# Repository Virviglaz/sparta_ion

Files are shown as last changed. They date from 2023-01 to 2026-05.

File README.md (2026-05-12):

# Sparta ION Repair & Restoration Project

This project is a functional, production-ready fork of the [InfantEudora/sparta_ion](https://github.com) repository.

## Overview

This repository implements a custom approach to repairing and restoring the functionality of all generations of the e-bikes popular in the Netherlands that feature the iconic **"banana-shaped" battery** and a **rear hub motor** (e.g., Sparta ION, Batavus, Koga).

## What's Inside

Everything needed to replicate or repair the electronics is included:

*   **Schematics:** Detailed circuit diagrams.
*   **PCB Files:** Design files ready for manufacturing (Gerber files).
*   **Firmware:** Source code and binaries for the microcontrollers.
*   **Documentation:** Step-by-step instructions for assembly, flashing, and system configuration. (in progress)

## Getting Started

1.  Review the **ion2\HW** to understand the hardware modifications.
2.  Order PCBs using the provided files in the `ion2\HW\BATT_ctrl_v3\Gerbers3.4` directory.
3.  Flash the microcontrollers using the code in the `ion2\batt_ctrl` and `ion2\bldc_mmu_firmware` folders.
4.  Follow the **ion2\docs** for final installation and tuning.

## Acknowledgments

This work is based on the original research and development found in the [sparta_ion](https://github.com) project.
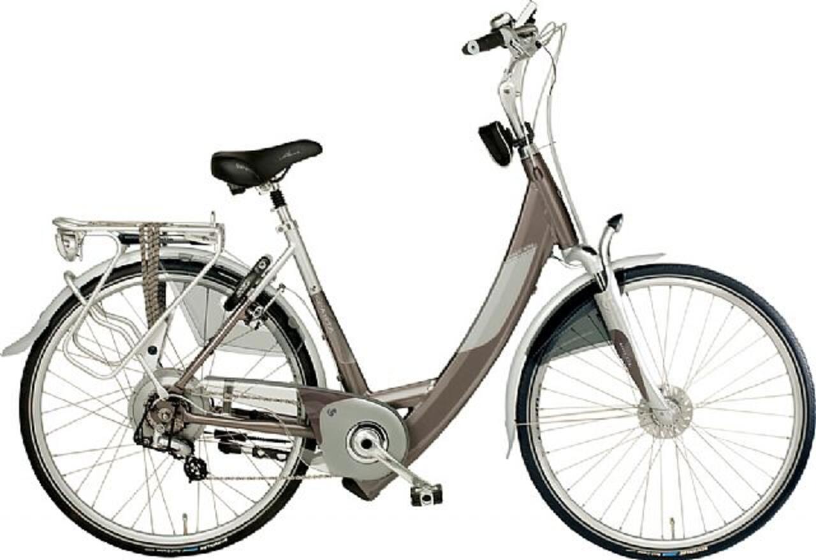
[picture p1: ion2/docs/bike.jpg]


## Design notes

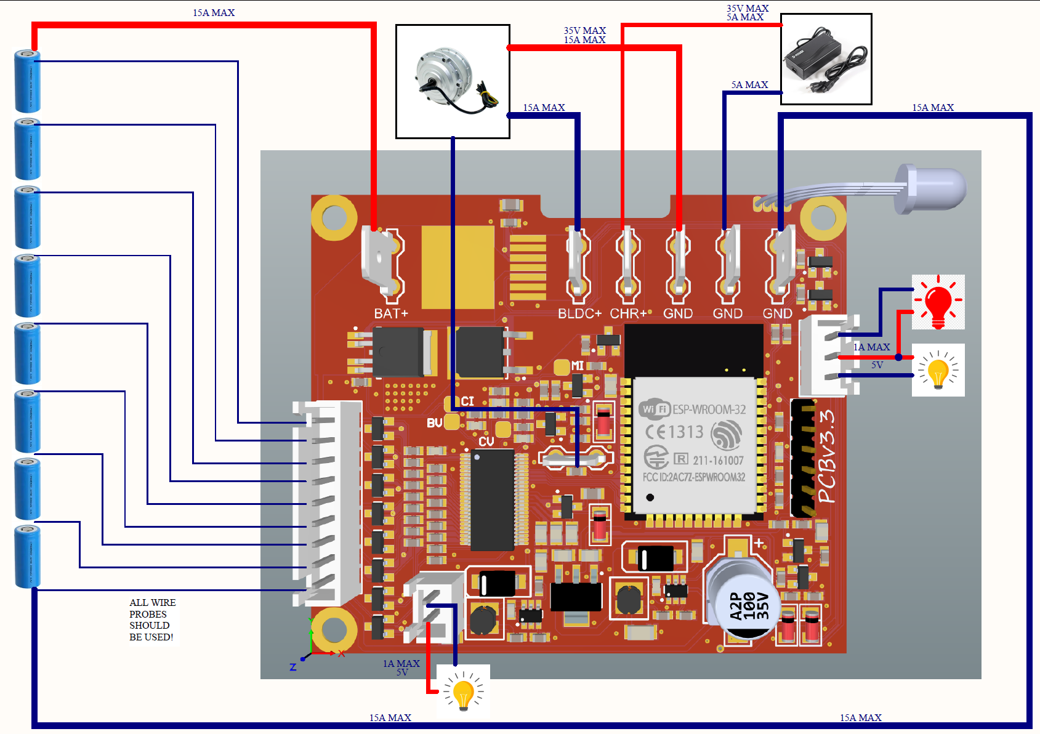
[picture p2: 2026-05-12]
ion2/docs/batt_ctrl_schematic.PNG

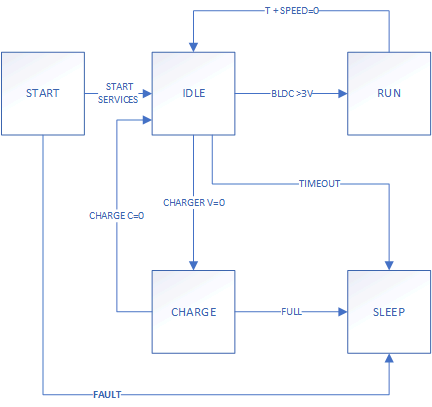
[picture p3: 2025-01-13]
ion2/docs/app_state_machine.png

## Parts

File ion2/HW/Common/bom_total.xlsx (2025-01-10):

Comment | Designator | Footprint | JLCPCB Part # | Qnty BLDC | Qnty BMS | sum | ordered
100 |  | 0603 | C2076611 | 6 | 0 | 6 | 60
4k7 |  |  | RT0603CRD074K7L | 1 | 1 | 2 | 20
1k 1% |  |  | MCT06030C1001FP500 | 1 | 3 | 4 | 40
10k 1% |  |  | C304079 | 3 | 3 | 6 | 60
390k |  |  | C403198 | 1 | 1 | 2 | 20
1k |  |  | C965150 | 11 | 12 | 23 | 230
10k |  |  | C465463 | 2 | 7 | 9 | 90
270k |  |  | C137642 | 1 | 0 | 1 | 10
220 |  |  | C5140263 | 1 | 0 | 1 | 10
47k |  |  | C2934399 | 1 | 1 | 2 | 20
100k 1% |  |  | C319967 | 0 | 2 | 2 | 20
100k |  |  | C319967 | 0 | 2 | 2 | 20
56k |  |  | C278629 | 0 | 2 | 2 | 20
100n |  |  | C323570 | 7 | 16 | 23 | 230
22 |  | 0805 | C3016596 | 0 | 8 | 8 | 80
6u8 |  | 0805 | C39060 | 0 | 9 | 9 | 90

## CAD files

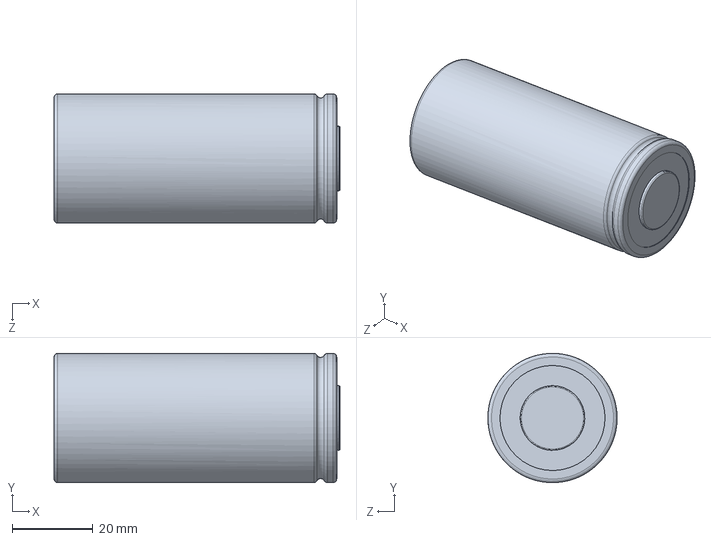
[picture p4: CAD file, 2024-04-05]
ion2/HW/SolidWorks/BatteryAssy1.SLDASM
70.8 x 32.0 x 32.0 mm

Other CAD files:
ion2/HW/SolidWorks/LiFePo4_32700.SLDPRT

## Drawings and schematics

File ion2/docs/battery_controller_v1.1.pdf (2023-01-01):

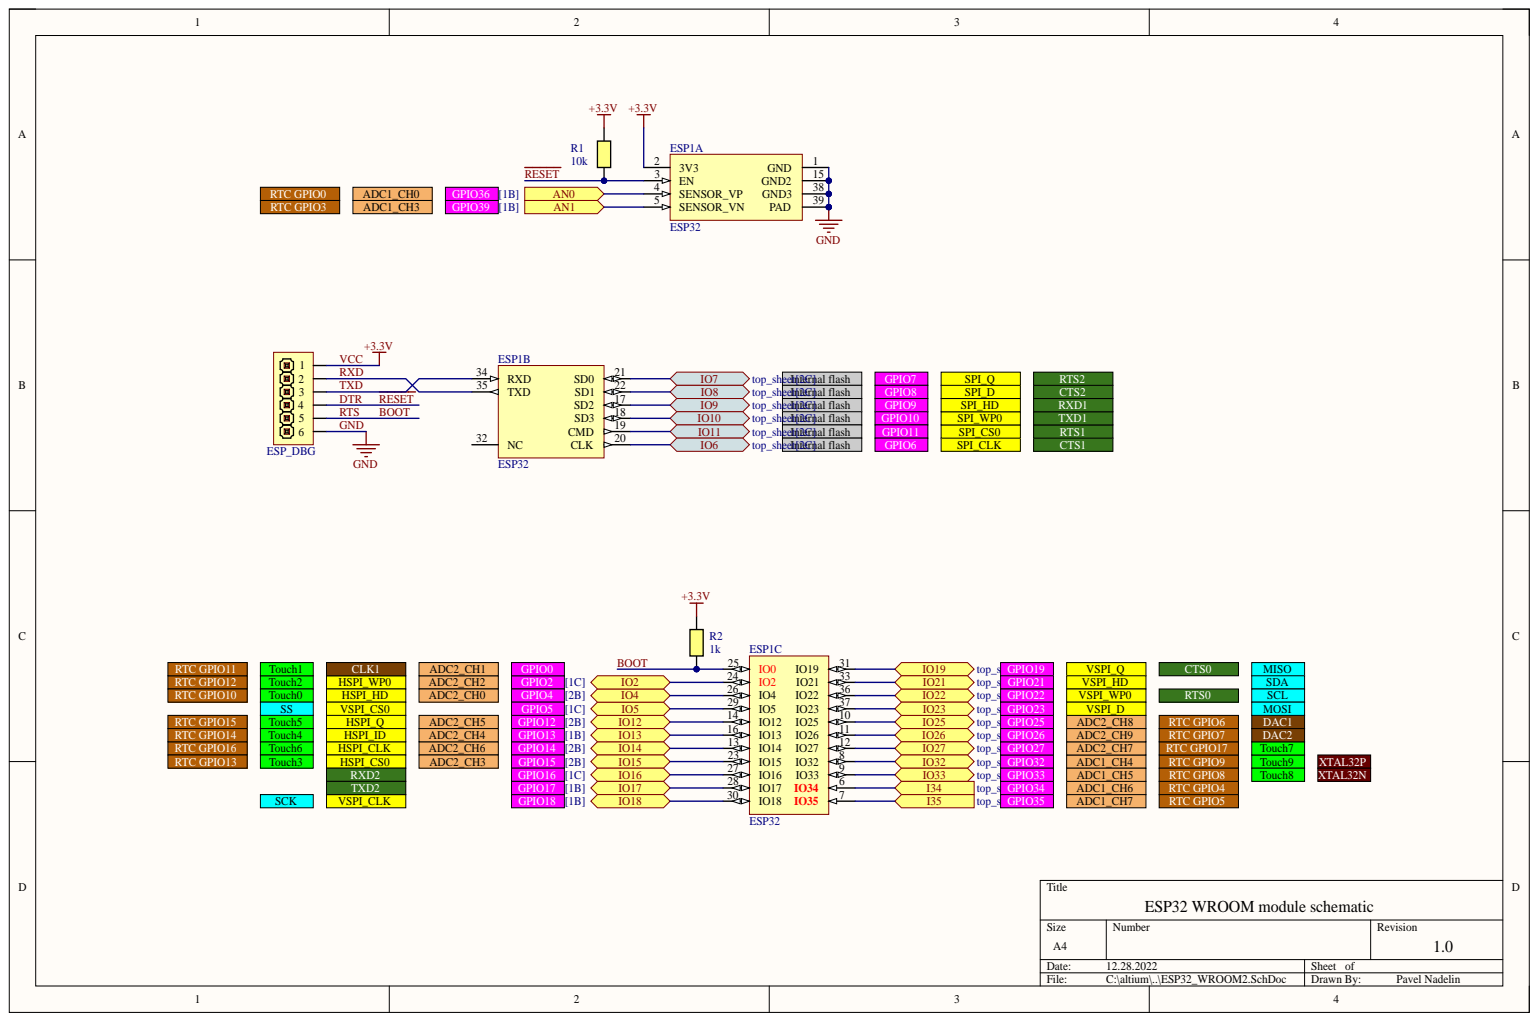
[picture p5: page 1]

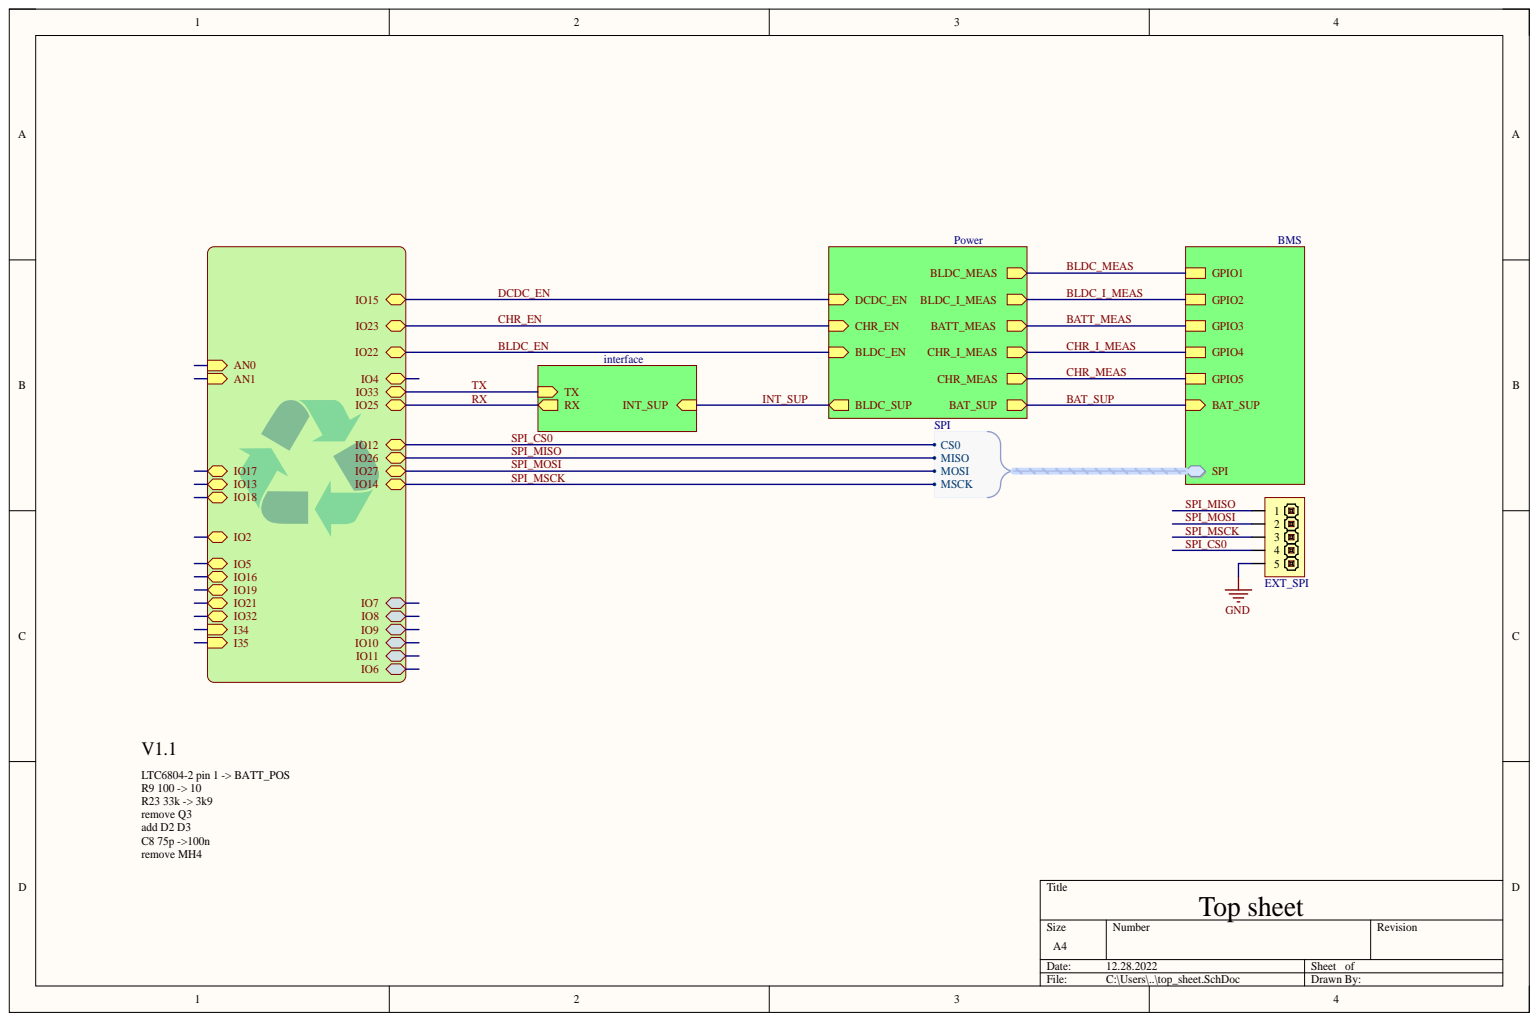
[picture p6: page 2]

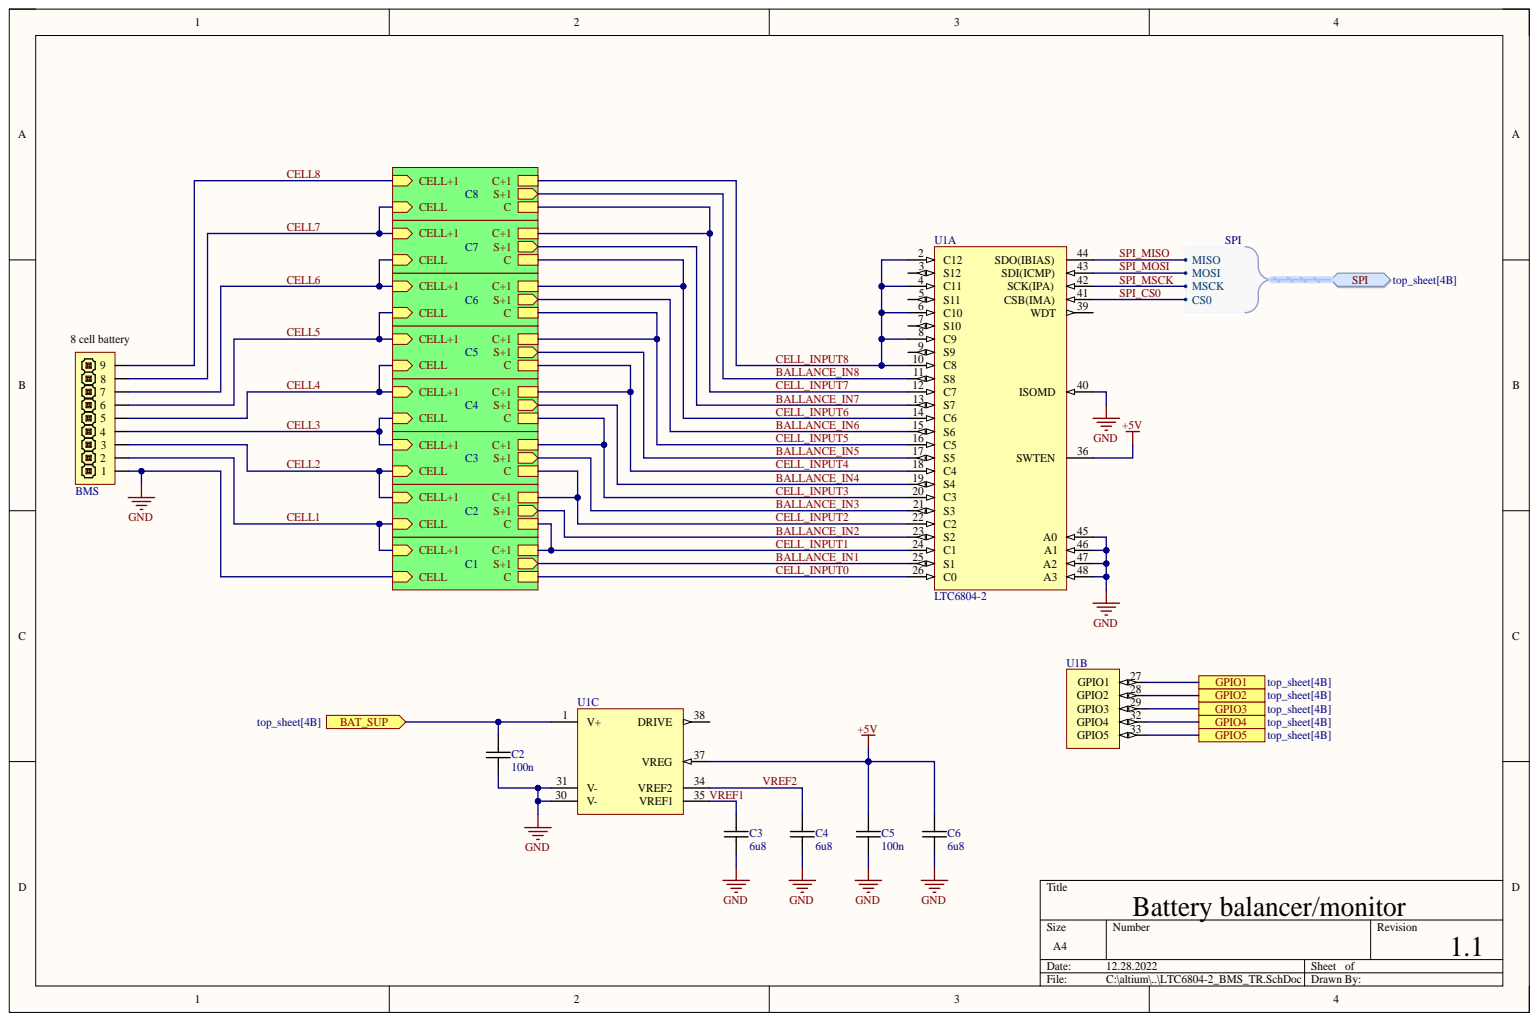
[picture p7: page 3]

CELL_INPUT8 | | | C8 10
BALLANCE_IN8 | 1 1

CELL4 | | C4 S+1 | | CELL_INPUT7 | | C7 12

BALLANCE_IN7 | | | S7 13
CELL_INPUT6 | | | C6 14

CELL3 | | | BALLANCE_IN6 | | S6 15

C3 S+1 | | CELL_INPUT5 | | C5 16

BALLANCE_IN5 | | | S5 17

CELL2 | | CELL_INPUT4 | | C4 18

GND | CELL1 | | | | BALLANCE_IN4 | | S4 19

C2 S+1 | | CELL_INPUT3 | | C3 20

BALLANCE_IN3 | | | S3 21
CELL_INPUT2 | | | C2 22
BALLANCE_IN2 | | S2 23

C1 S+1 | | CELL_INPUT1 | C1 24

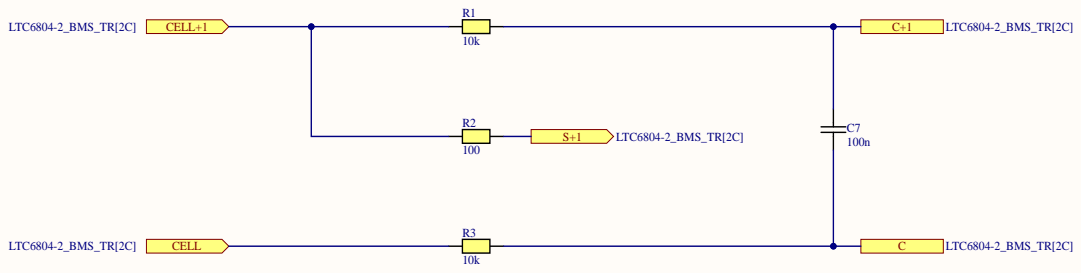
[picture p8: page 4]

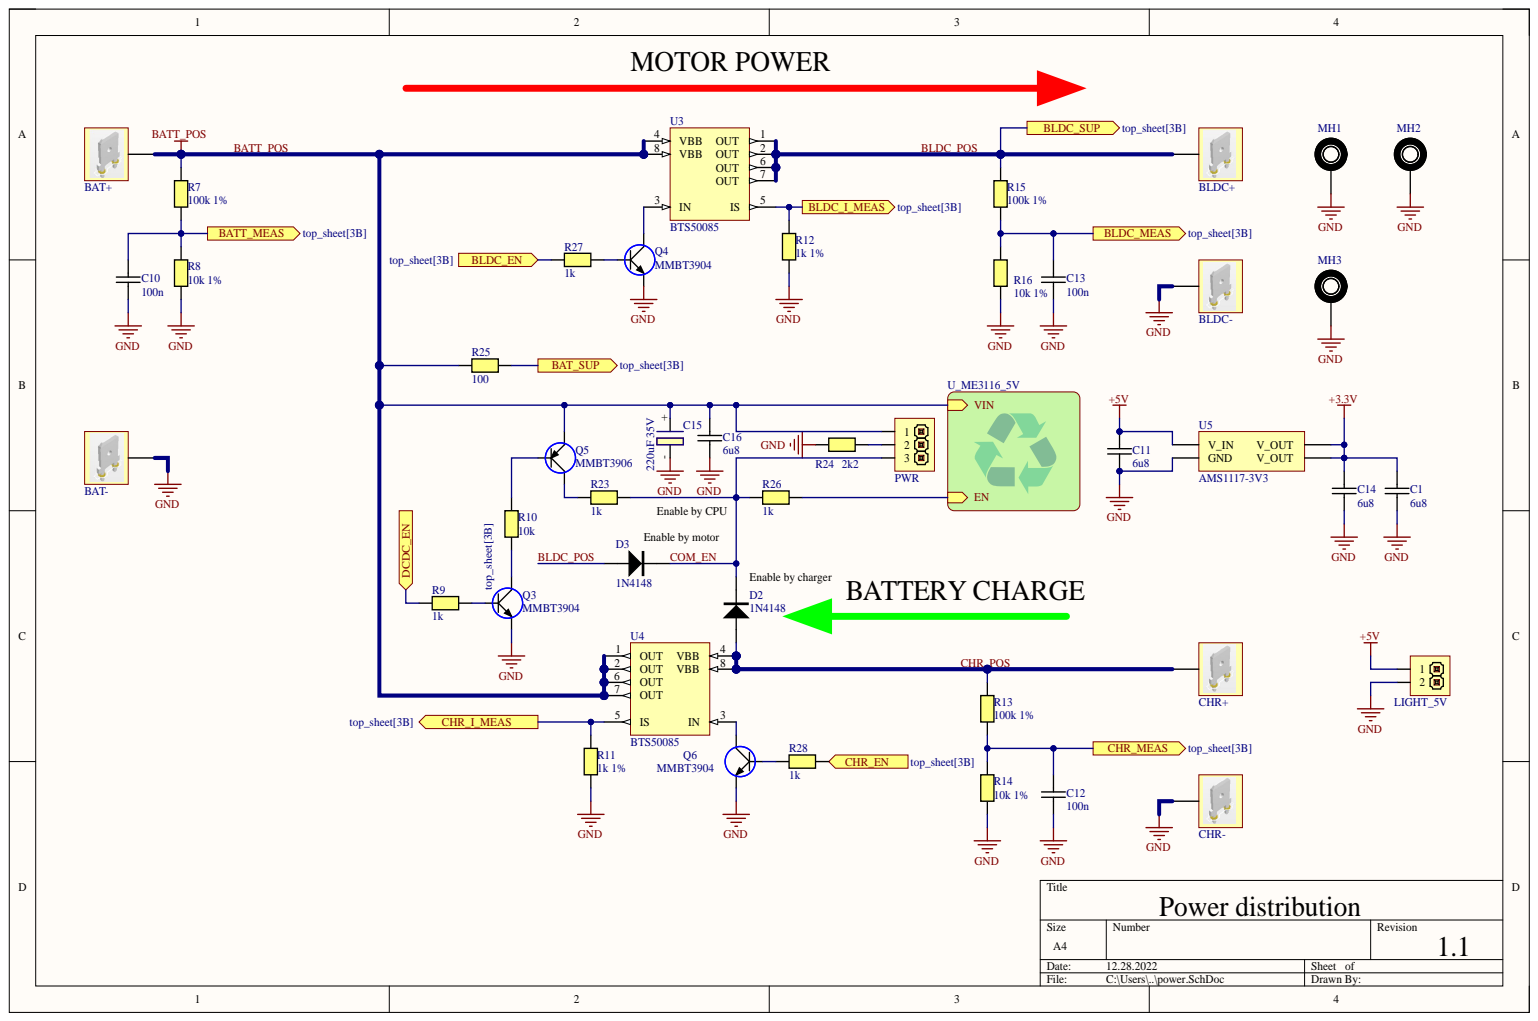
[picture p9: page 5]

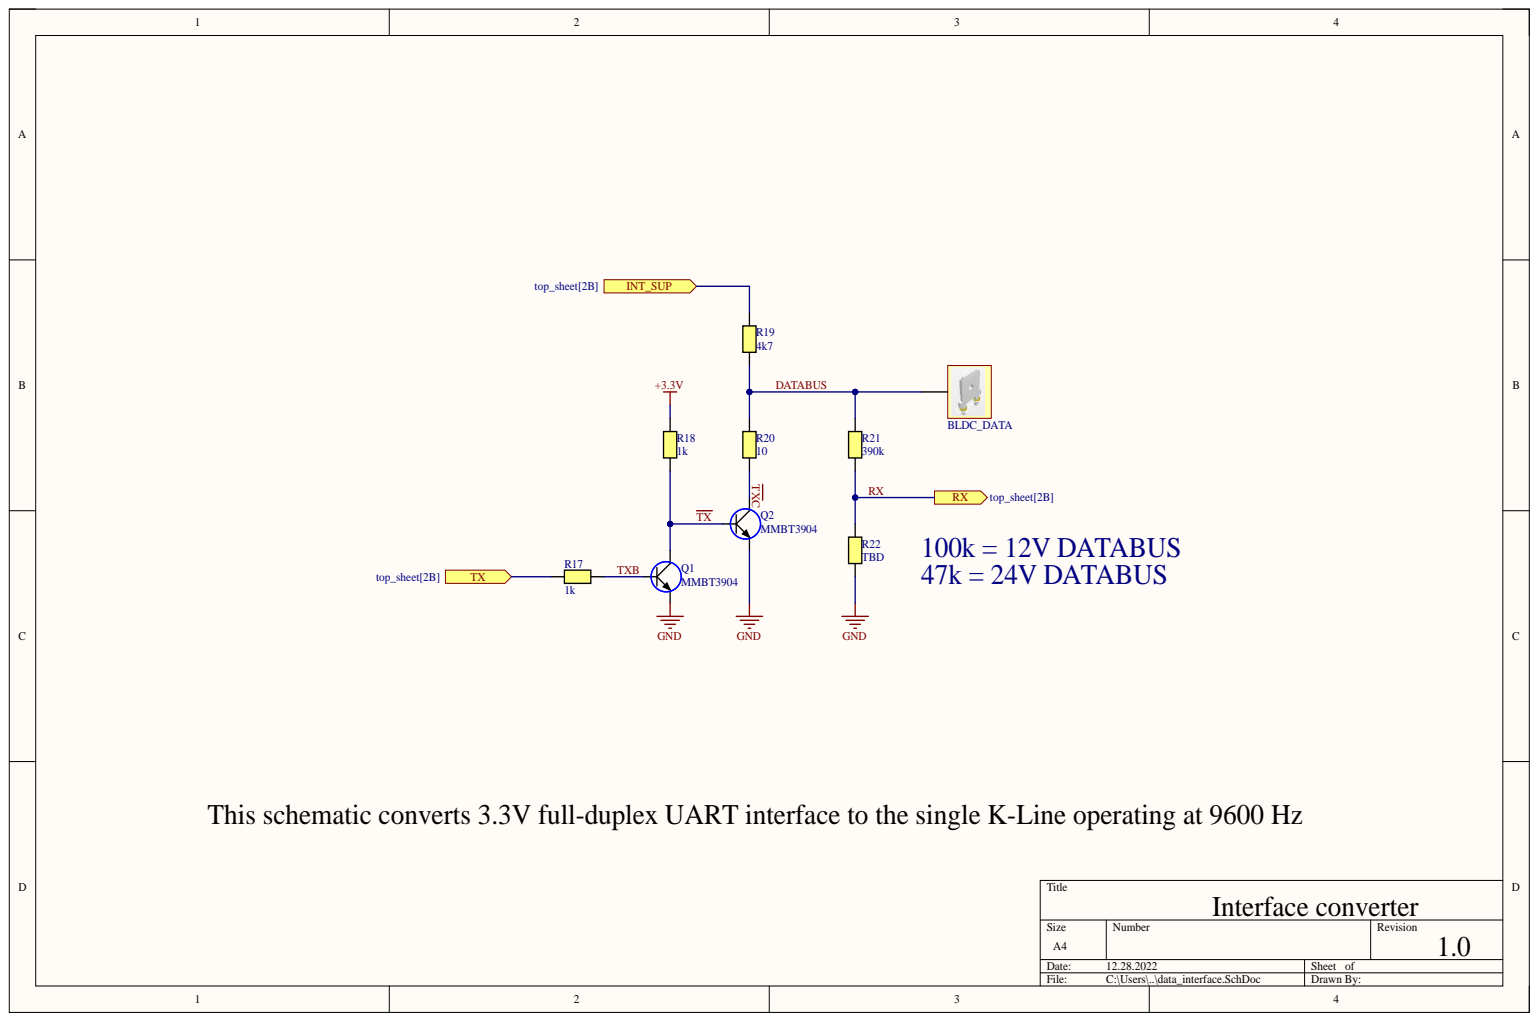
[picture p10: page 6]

This schematic converts 3.3V full-duplex UART interface to the single K-Line operating at 9600 Hz

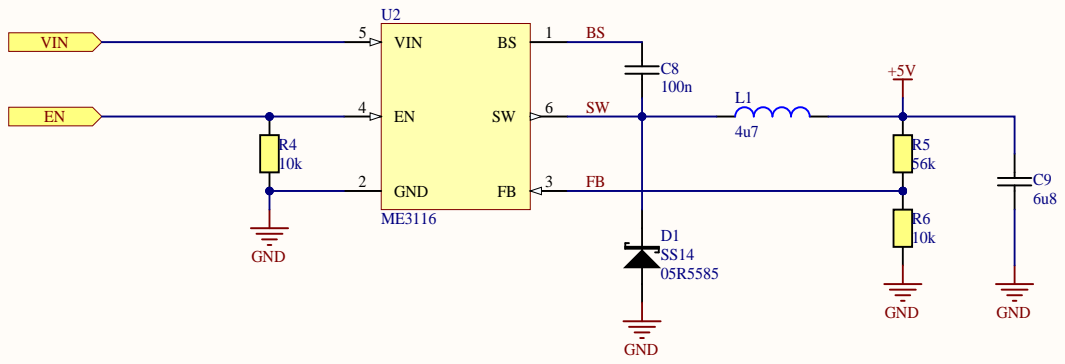
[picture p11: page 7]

Title
DC/DC Voltage converter 1A rated

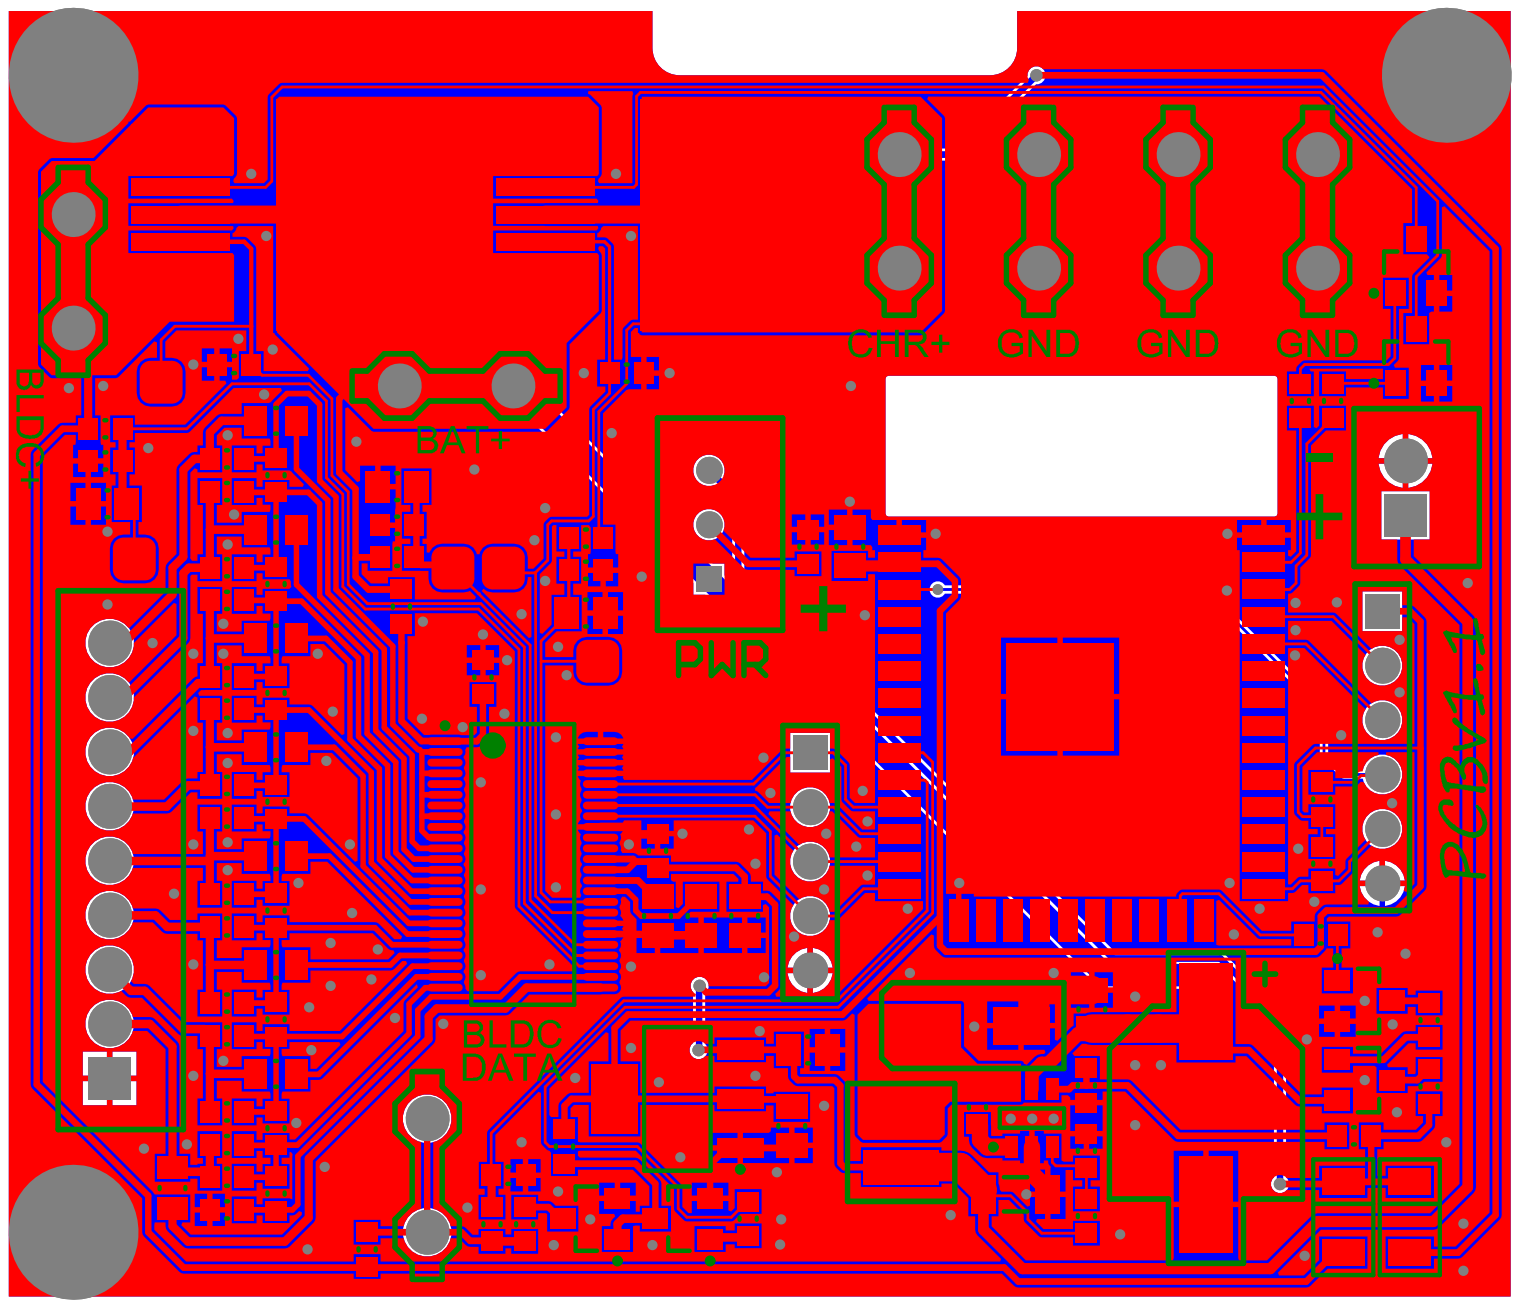
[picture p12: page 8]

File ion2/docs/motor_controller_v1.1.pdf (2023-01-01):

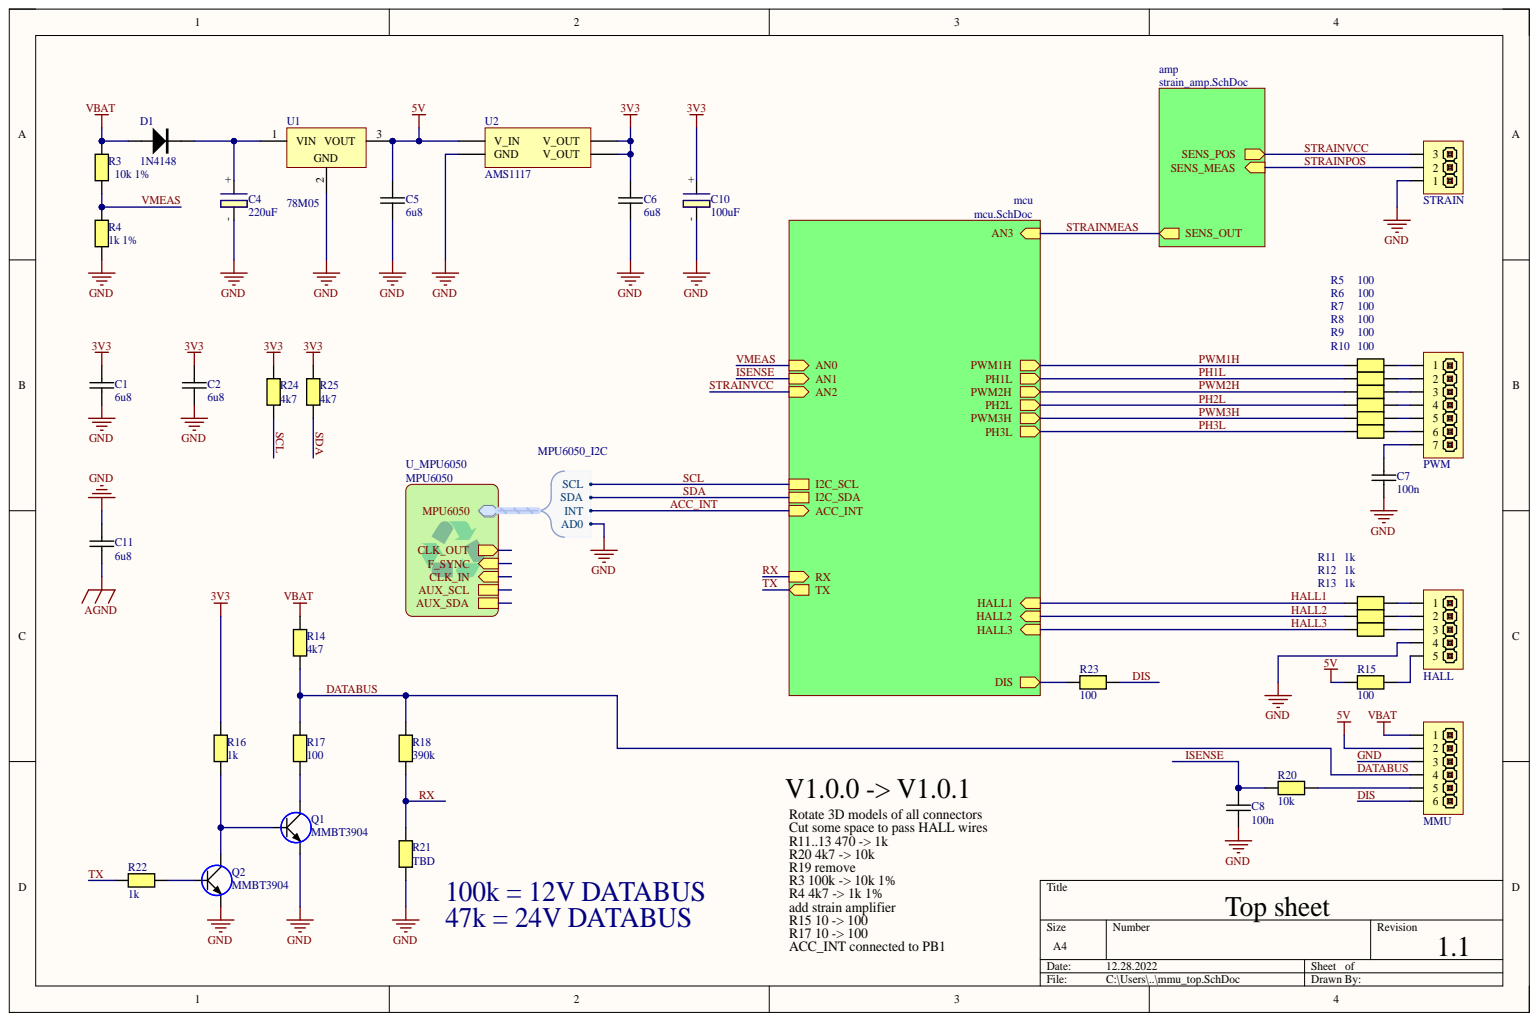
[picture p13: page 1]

Rotate 3D models of all connectors
Cut some space to pass HALL wires
R19 remove R3 100k -> 10k 1%

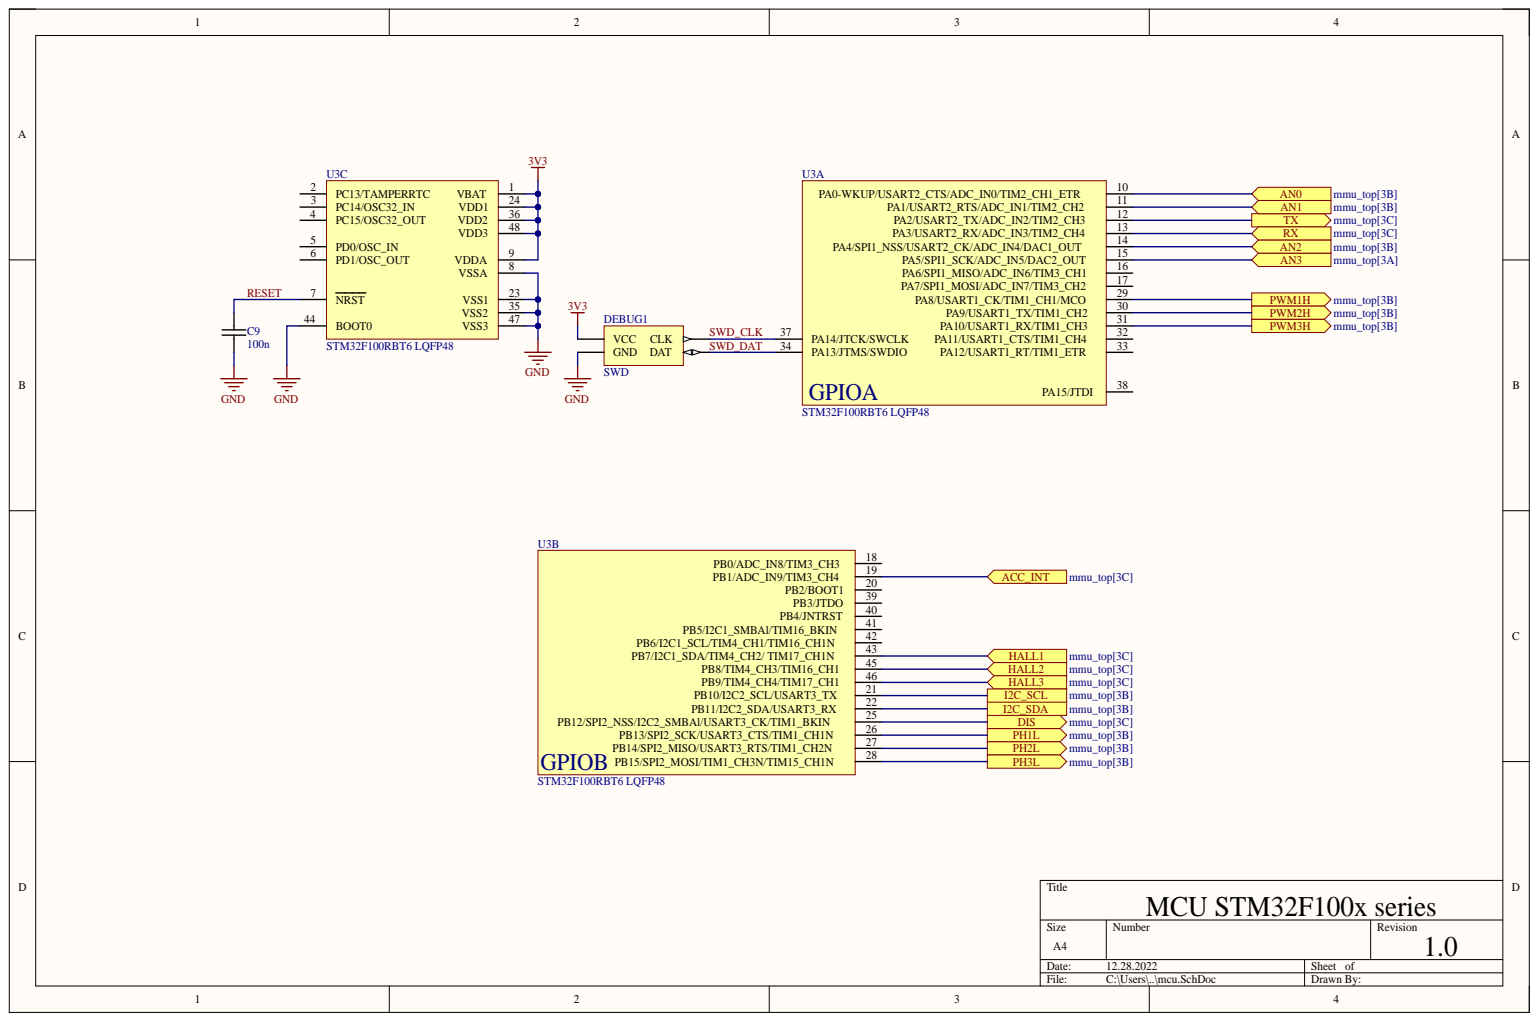
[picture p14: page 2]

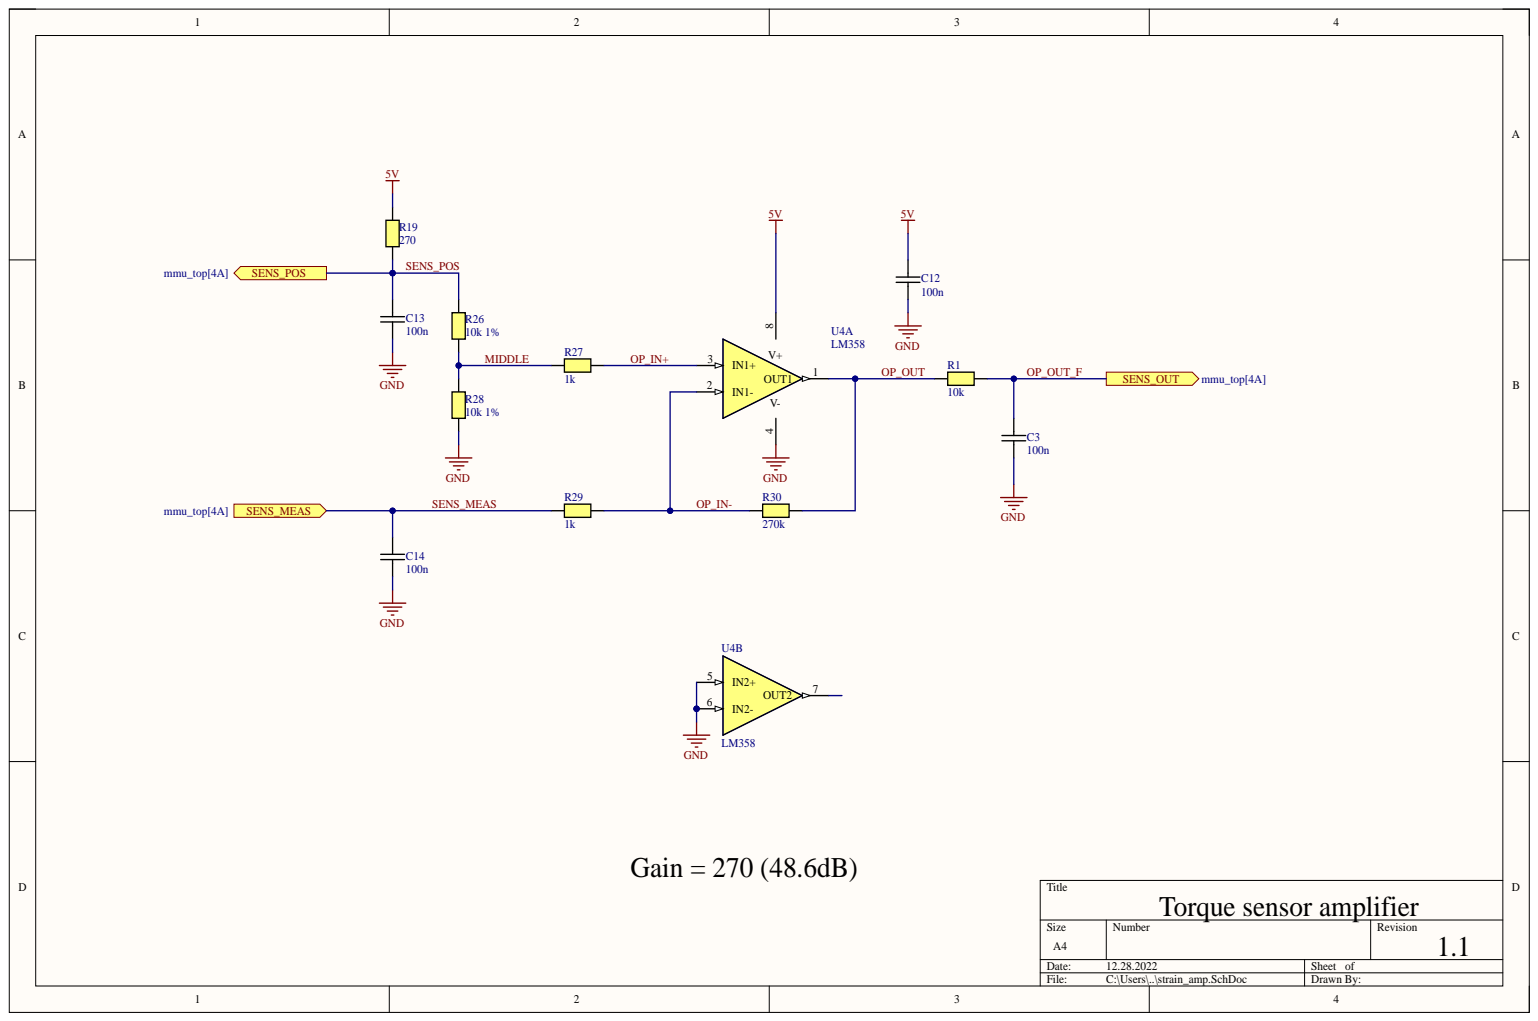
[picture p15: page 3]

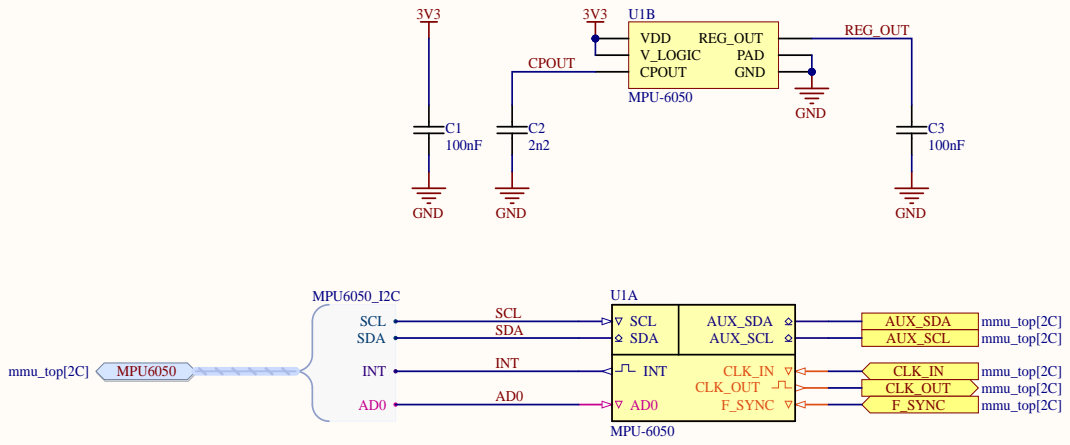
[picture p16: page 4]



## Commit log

2022-12-27 initial
    battery controller PCBv1.1
    bldc controller PCBv1.0
    [BATT_ctrl.PrjPcb, BLDC_ctrl.PrjPcb, battery_monitor.SchDoc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]
2023-01-01 [v1.1] add documentation and release version 1.1
    [BATT_ctrl.PrjPcb, BLDC_ctrl.PrjPcb, cell_ballance_r.SchDoc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]
2023-09-03 [stage] works fine
    [BLDC_ctrl.PrjPcb, mmu_pcb_v1.2.PcbDoc, mmu_top.SchDoc]
2023-09-05 [PCBv2.1] pre-release of new battery controller board
    [BATT_ctrl_v2.1.PrjPcb, battery_monitor.SchDoc, cell_ballance.SchDoc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]
2023-10-04 add capacitor to light load add resistor to enable of light ic
    [BATT_ctrl_v2.1.PrjPcb]
2023-11-11 [stage] stage commit
    know issues: torque sensor value drift over time
2023-11-29 [stage] works
2024-03-10 Release
    BATT_ctrl v2.2 (light ctrl + power schottky diode for charging)
    BLDC_ctrl v1.2 (torque gain amplifier + soft pwm resistors)
    [BATT_ctrl_v2.1.PrjPcb, BATT_ctrl_v2.2.PrjPcb, BLDC_ctrl.PrjPcb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]
2024-03-14 [BATT_ctrl] added v2.2
    [BATT_ctrl_v2.2.PrjPcb, battery_monitor.SchDoc, cell_ballance.SchDoc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]
2024-03-21 [pcb2.3] pre-release
    [BATT_ctrl_v2.2.PrjPcb, battery_monitor.SchDoc, cell_ballance.SchDoc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]
2024-04-05 [HW 2.3] fix cells balancing
    [BATT_ctrl_v2.3.PrjPcb, BatteryAssy1.SLDASM, power.SchDoc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]
2024-04-13 [pcb2.3] all issues solved
    [BATT_ctrl_v2.3.PrjPcb, power.SchDoc, top_sheet.SchDoc]
2025-01-13 [PCB2.4] release PCB2.4
    [power.SchDoc, top_sheet.SchDoc]
2025-02-23 [PCB1.2] update R16 value
    [mmu_top.SchDoc]
2025-04-04 [pcb v2.5] add resistor to power supply pin of ADC
    [BATT_ctrl_v2.3.PrjPcb, mmu_top.SchDoc, top_sheet.SchDoc]
2025-05-05 [v3.0] release BATT_CTRL v3.0
    [BATT_ctrl_v3.PrjPcb, battery_monitor.SchDoc, cell_ballance.SchDoc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]
2025-05-28 [board v3.2] make possible switch off the light
    TODO: add support in code
    [BATT_ctrl_v3.PrjPcb, power.SchDoc, top_sheet.SchDoc]
2025-05-31 [pcb v3.3] pre-release
    -add bracke light control
    -add lights off control
    [power.SchDoc, top_sheet.SchDoc]
2025-06-06 stage
    [v0.999a] add brake and light control for pcb v3.3
    [v0.998a] default support level is 2
    [TIM2] 8MHz->16MHz
2025-06-09 Stage
    [TIM2] 8MHz->16MHz make sine generator more smooth
    [IRQ] clear IRQ after handling
    [BLDC] use 11 points pwm sine generator
    [BLDC] use 6 points per hall trigger
2025-08-04 v3.3 PCB
    [BATT_ctrl_v3.PrjPcb, mmu_top.SchDoc, top_sheet.SchDoc]
2025-09-06 added overal schematic for battery controller unit
    [BATT_ctrl_v3.PrjPcb, OveralSchematic.SchDoc]
2025-09-08 added schematic
2025-09-21 [v3.4] PCB change anounced
    Fix burning Q201 and D201
    [BATT_ctrl_v3.PrjPcb, power.SchDoc, top_sheet.SchDoc]
2025-10-11 [pcb3.4] use 2-pin connector for brake light
    [batt_ctrl_pcb_v3.4.PcbDoc, power.SchDoc]
2025-12-05 [PCBv3.4] released
    [BATT_ctrl_v3.PrjPcb, batt_ctrl_pcb_v3.4.PcbDoc]
